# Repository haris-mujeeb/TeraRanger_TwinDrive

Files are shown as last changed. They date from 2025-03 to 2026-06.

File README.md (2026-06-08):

# Autonomous Maze Solving Robot 🤖

This project features a two-wheeled, self-balancing robot capable of autonomous navigation and maze solving. It uses a host-PC-based algorithm to build a 2D map of its environment in real-time.

The robot's hardware is a custom-designed, differential-drive platform based on an **Arduino Nano** for real-time balancing control and an **ESP32-S3** as a central communication hub. It uses a **TeraRanger Multiflex** Time-of-Flight (ToF) sensor array for 2D environmental mapping.

RobotFinalAssembly1

-----

## Demo
https://github.com/user-attachments/assets/0ca18e00-be7d-4444-9bbe-24fa2c01fbb0

-----

## System Architecture


-----

## ✨ Key Features
  * **Dynamic Self-Balancing**: Implements a robust **Multi-rate PID control** algorithm to ensure stable balancing and precise locomotion. The pitch control loop uses an **Adaptive Derivative Gain** to achieve high stability while eliminating jitter.
  * **Advanced Sensor Fusion**: Utilizes an **Extended Kalman Filter (EKF)** for accurate state estimation. It fuses data from the **MPU-6050** IMU (attitude) and **Hall-effect motor encoders** (odometry) to get a reliable estimate of the robot's pitch angle and position.
  * **Real-time 2D Mapping**: The host PC application integrates robot odometry with the **TeraRanger Multiflex** ToF sensor readings, building a 2D point cloud map of the environment on the fly.
  * **Live Data Visualization**: A custom **PyQtGraph** application provides a rich, interactive 2D plot displaying the robot's estimated position, historical path, and the mapped environmental points.
  * **Wi-Fi Communication Hub**: The ESP32-S3 acts as a **Soft Access Point (SoftAP)**, creating its own Wi-Fi network. It streams sensor telemetry and receives control commands over a low-latency **TCP socket** connection.
  * **Autonomous & Manual Control**: The robot can be driven manually via keyboard commands or operate autonomously, using the generated map and a **wall-following algorithm** to solve mazes.

-----

## 🛠️ System Architecture & Technologies

The system is split into two main parts: the on-board embedded controllers and the host PC application.

### 1\. Robot Hardware & Firmware (C++ / PlatformIO)

| Component | Role | Details |
| :--- | :--- | :--- |
| **Mobile Base** | **Arduino Nano** | The low-level controller responsible for real-time balancing and motion. It runs the high-frequency, multi-rate PID control loops. |
| **Comm. Hub** | **ESP32-S3-DevKitC-1** | The high-level controller and main hub. It aggregates data from the Arduino Nano and ToF sensors, and manages the Wi-Fi (SoftAP) TCP connection to the PC. |
| **Attitude Sensor** | **MPU-6050 IMU** | Provides 6-axis accelerometer and gyroscope data for orientation and pitch angle estimation. |
| **Mapping Sensor** | **TeraRanger Multiflex** | An array of 8 ToF (Time-of-Flight) sensors used for 2D environmental mapping. |
| **Odometry Sensors** | **Hall-Effect Encoders** | Integrated into the DC motors, they provide precise odometry (distance and speed) measurements. |

### 2\. Host PC Application (Python)

  * **Logic**: **Python** for the main application, mapping algorithms, and maze-solving logic.
  * **GUI**: **PyQt5** for the application window and user controls.
  * **Visualization**: **PyQtGraph** for high-performance, real-time 2D plotting of the map and robot state.
  * **Data Processing**: **NumPy** for efficient numerical operations.

-----

## 📂 Project Structure

```
.
├── communication_hub_code/  # Firmware for the ESP32-S3 (Wi-Fi, Sensor Hub)
├── mobile_base_code/        # PlatformIO project for the Arduino Nano (Balancing, Motor Control)
├── tests/                   # Test scripts and code
├── videos/                  # Demo videos
├── .gitignore
├── LICENSE
├── logger_config.py         # Logging configuration
├── main.py                  # Main Python application entry point (Visualization)
├── mazeSolver.py            # Autonomous maze solving logic
├── README.md                # This file
├── requirements.txt         # Python dependencies
└── robotInterface.py        # Interface for robot (TCP) communication and control
```

-----

## 🚀 Installation & Setup

### 1\. Clone the Repository

```bash
git clone https://github.com/haris-mujeeb/Maze_Solver.git
cd Maze_Solver
```

### 2\. Install Python Dependencies

```bash
pip install -r requirements.txt
```

### 3\. Robot Firmware Setup (Crucial)

You will need **[PlatformIO](https://platformio.org/)** (ideally as a VS Code extension) to build and upload the firmware for both microcontrollers.

#### A. Mobile Base (Arduino Nano)

This firmware handles the core self-balancing and motor control.

1.  Open the `mobile_base_code/` directory in VS Code with PlatformIO.
2.  Connect your **Arduino Nano**.
3.  Build and upload the project.

#### B. Communication Hub (ESP32-S3)

This firmware manages sensor data aggregation and Wi-Fi communication.

1.  Open the `communication_hub_code/` directory in VS Code with PlatformIO.
2.  Connect your **ESP32-S3-DevKitC-1**.
3.  Build and upload the project.
4.  This firmware will create a Wi-Fi Access Point (SoftAP). The default IP address is typically `192.168.4.1`.

-----

## ⚙️ Configuration

The network settings for Wi-Fi communication are defined in `main.py`. These must match your robot's network configuration.

```python
# main.py
RECEIVE_HOST = '0.0.0.0'  # PC: Listen on all available interfaces for incoming robot data
RECEIVE_PORT = 12346      # PC: Port for receiving telemetry data (via TCP)
SEND_HOST = '192.168.4.1' # ROBOT'S IP: Default IP for ESP32-S3 SoftAP mode
SEND_PORT = 12345         # ROBOT'S PORT: Port for sending commands (via TCP)
```

  * **`SEND_HOST`**: This **must be the IP address of your ESP32-S3**. If you are connecting your PC directly to the robot's Wi-Fi network (SoftAP mode), this will be `192.168.4.1`.
  * Ensure the ports match those configured in the ESP32-S3 firmware.

-----

## 🕹️ Usage

1.  **Power on the robot**. The Arduino Nano will begin balancing, and the ESP32-S3 will start its Wi-Fi Access Point.
2.  **Connect your PC** to the Wi-Fi network created by the ESP32-S3.
3.  **Run the main application** on your host PC:
    ```bash
    python main.py
    ```
4.  **Control the robot:**
      * The PyQtGraph application will launch, showing the live visualization.
      * Use the following keyboard commands for manual control:
          * **W**: Move forward
          * **S**: Move backward
          * **A**: Turn left
          * **D**: Turn right
          * **R**: Stop
          * **G**: Go to a manually entered target (prompts for X, Y coordinates)
      * You can also **left-click on the plot** to set a target position for the robot to navigate to autonomously.

## Contributing

Contributions are welcome\! Please feel free to submit a pull request or open an issue if you have any suggestions or find any bugs.

## License

This project is licensed under the MIT License. See the [LICENSE](https://www.google.com/search?q=LICENSE) file for details.

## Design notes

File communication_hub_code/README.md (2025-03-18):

Continuously sends telemetry data (robot yaw, distance, etc.) to connected clients and reponds to the commands for controlling the robot's movement (e.g., TURN, MOVE).

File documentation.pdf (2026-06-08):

## Universität Siegen Naturwissenschaftlich-Technische Fakultät Department Elektrotechnik und Informatik Lehrstuhl für Regelungs- und Steuerungstechnik

## Studienarbeit

# Design and Fabrication of Remotely

# Operated Two-Wheeled Self-Balancing

# Robot with Integrated ToF Sensor

# Array for 2D Mapping

by

Muhammad Haris Mujeeb

Matriculation number

1721876

Examiner

Prof. Dr.-Ing. habil. Michael Gerke

2nd Examiner

Dipl.-Ing. Nasser Gyagenda

Date of delivery

12.05.2025

Abstract—This report presents the design and implementation of a remotely controlled two-wheeled self-balancing robot with TeraRanger Multiflex, consisting of eight Time-of-Flight (ToF) sensors for two-dimensional (2D) environmental mapping. The system

architecture comprises a differential-drive mobile base, a ToF sensors array for spatial perception and an embedded communication and control hub for data integration and external interfacing. The mobile base consists of a pair of DC motors, an Arduino Nano microcontroller, an Inertial Measurement Unit (IMU) and Hall-effect rotary encoders to provide accurate state estimation. A Multi-rate Proportional-Integral-Derivative (PID)

control algorithm is employed to ensure stable balancing and precise locomotion control. The ESP32-S3-DevKitC-1 serves as the central communication and control hub, enabling efficient data exchange between the two-wheeled mobile base, the ToF sensor array, and external systems such as computers, microcontrollers, mobile devices, or cloud services. This setup facilitates real-time monitoring and remote control via Wi-Fi, thereby enhancing the system’s adaptability across various applications. The firmware for both the Arduino and ESP32-based microcontrollers was developed using PlatformIO (https://platformio.org/) and Arduino IDE. (https://www.arduino.cc/en/software) The

robot continuously transmits telemetry and ToF sensors data while receiving commands through Wi-Fi. The complete project, including source code and detailed documentation, is available at the following GitHub repositories:

- https://github.com/haris-mujeeb/Self-Balancing-Robot
- https://github.com/haris-mujeeb/TeraRanger-Multiflex-DEMO
- https://github.com/haris-mujeeb/TeraRanger_TwinDrive

i

## Contents

1 Introduction | 1
2 Project Objectives | 2
3 Literature Review | 2
4 Mathematical Modelling | 4
5 Implementation | 7
6 Sensor Fusion | 16
7 Motor Control | 21

ii

8 Front Obstacle Detection | 30
9 Communication Hub | 36
10 Conclusion | 41
11 Future Work and Improvements | 42
Appendices | 43
A Calculation of the system’s transfer functions | 43
B Calculation for Kalman Filter | 46

iii

iv

## List of Figures

Fig. 1 | Forecast of the MEMS market value in billions of US dollars by year. Reproduced
| from an open-access source [3] | | 1
Fig. 2 | ELEGOO Tumbler used as the mobile base for this project [7] | | 3
Fig. 3 | TeraRanger Multiflex circular mount [18] | | 3
Fig. 4 | ESP32-S3-DevKitC-1-N8R8 from Espressif Systems[19] | | 3
Fig. 5 | Simplified inverted pendulum model for the balancing robot [8] | | 4
Fig. 6 | Pole-zero map of the open loop system Gψ revealing a pole in the right half plane. | 5
Fig. 7 | A simplified block diagram of the system architecture | | 7
Fig. 8 | A simplified flow diagram of the system architecture | | 8
Fig. 9 | (a) ATmega328p microcontroller by Microchip [21]; (b) Arduino Nano board by
| Arduino [22] | | 9
Fig. 10 ELEGOO chargeable battery pack | | 10
Fig. 11 Schematic of the voltage divider circuit utilised in this project. The voltage VM is
| connected to the positive terminal of the battery, while VOL is connected to the
| Arduino Nano A2 pin [7] | | 10
Fig. 12 MPU-6050 6-axis IMU [24] | | 11
Fig. 13 (a) TB6612FNG motor driver [26]; (b) SN74LVC2G14 dual Schmitt-trigger
| inverter [27] | | 12
Fig. 14 Target characteristics for TB6612FNG [25] | | 12
Fig. 15 Schmitt trigger output without hysteresis (left) and with hysteresis (right) [28]. . . | 13

Fig. 16 Using SN74LVC2G14 in conjunction with TB6612FNG to reduce MCU pin usage
| and noise filtering [7] | | 13
Fig. 17 NHYTech GA37 520 DC motor [29] | | 13
Fig. 18 (a) IR204C-A infrared LED [31]; (b) IRM-56384 infrared reciever [32] | | 14
Fig. 19 (a) HC-SR04 ultrasonic distance sensor [30]; (b) Bluetooth module [33] | | 14

Fig. 20 Pitch angle calculated using a complementary filter with α = 0.9. It can be
| observed that the high frequency accelerometer noise (circled in red) are filtered
| properly. And similarly the low frequency integration errors of the gyroscope (red)
| are removed over longer interval of time | | 17
Fig. 21 Block diagram for pitch angle ψ control | | 21
Fig. 22 A simplified flow diagram of the multi-rate PID control loop used | | 24
Fig. 23 Output values calculated by the pitch angle PD controller at Kpψ = 55 and Kdψ =
| 1.25. The data was recorded at baud rate of 115200 | | 25
Fig. 24 Output values calculated by the pitch angle PD controller at Kpψ = 55 and Kdψ =
| 0.75. Data recorded at baud rate of 115200 | | 25
Fig. 25 Output values calculated by the pitch angle PD controller with an adaptive
| derivative gain at Kpψ = 55 and Kdψ = 0.75 ∼ 1.25. The data was recorded
| at baud rate of 115200 | | 26
Fig. 26 Yaw angle control system response at Kp = 2.5 and Kd = 0.5 for angle varying
| from −20 deg to +20 deg. The data was recorded at baud rate of 115200 | | 27

v

Fig. 27 Position control system response with Kpx = 0.26 and Kdx = 20 for a displacement
of −600 mm to +300 mm. Data recorded at baud rate of 115200 | | 29
Fig. 28 A simplified diagram of the motor control loop [35] | | 29
Fig. 29 The received raw data from the TerraRanger Multiflex via UART | | 38
Fig. 30 Real-time sensor data visualization in a polar plot | | 39
Fig. 31 Final assembly of the remotely operated two-wheeled robot with TeraRanger
Multiflex | 41
Fig. 32 Free-body diagram of the simplified system with cart and pendulum [35]. Where, x axis is along the horizontal axis and y axis is along the vertical axis and ψ = π − θ. 43

vi

## List of Tables

Tab. 1 | UART Communication Configuration | | 15
Tab. 2 | I2C Communication Methods | | 36
Tab. 3 | UART Communication Methods | | 37
Tab. 4 | List of Commands and Corresponding Values | | 37

vii

1. Introduction

## 1. Introduction

The World Robotics report reveals a record 4.28 million operational industrial robots globally in 2023, with Asia leading installations at 70%, driven primarily by China’s significant market share, while

overall demand for robots is expected to stabilize and grow in the coming years despite geopolitical uncertainties [1]. The mobile robot market, particularly for autonomous mobile robots (AMRs), is

experiencing rapid growth across industrial and commercial sectors, with the overall AMR market projected to grow at 24% annually—from $19 billion in 2018 to $54 billion by 2023 [2]. Driven

initially by automotive and electronics sectors, demand is now expanding into logistics, healthcare, and consumer goods, with Europe leading the market and significant contributions from the USA and China [2].
Over the past decade, advancements in Micro-Electro-Mechanical Systems (MEMS) and embedded

computing have revolutionized the design and functionality of robots. Membrane-based MEMS, such as pressure sensors, radio frequency MEMS, accelerometers, microphones, gyroscopes and inertial combos are commercially the most relevant devices by producing the most revenue as shown in Fig. 1.

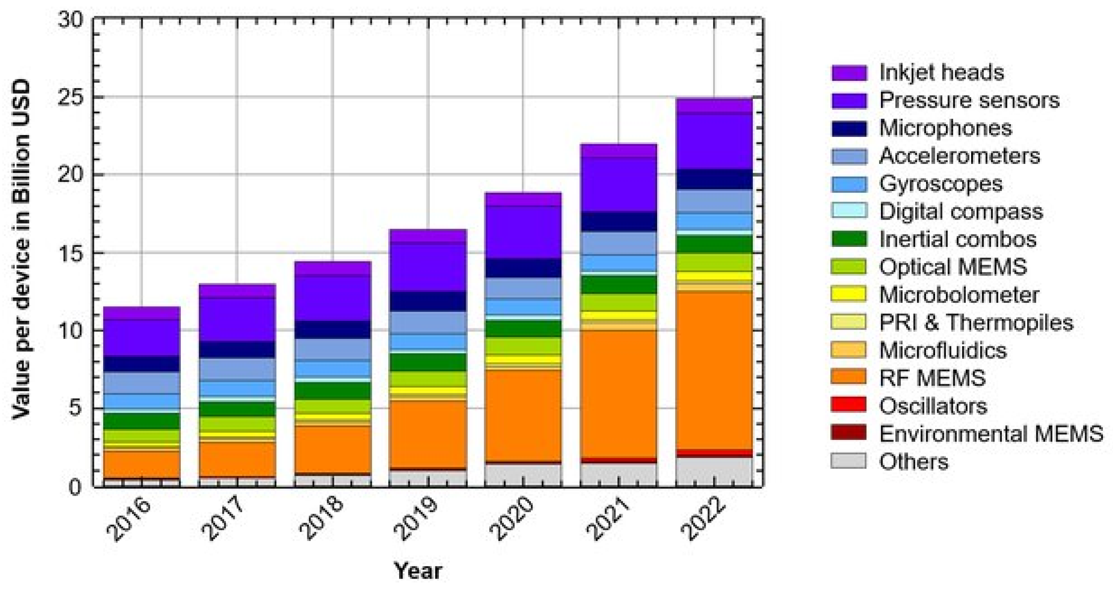
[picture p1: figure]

Figure 1: Forecast of the MEMS market value in billions of US dollars by year. Reproduced from an open-access source [3].

The worldwide MEMS market is expected to grow to $64.15 billion by 2035 [4]. These advancements

in MEMS and embedded computing have also revolutionized the design and functionality of mobile robots. For instance, the introduction of gyros, accelerometers, and other sensors has enabled these robots to achieve higher levels of balance and stability. One interesting area of research is the integration of cost effective Time-of-Flight (ToF) sensors, a type of Optical MEMS sensors, with

mobile base. These sensors are particularly useful for applications requiring 2D mapping, such as navigation, localization, and obstacle detection.
Therefore, research into the design and fabrication of a low-cost, user-friendly mobile robot base equipped with ToF sensors is both timely and strategic. Such a platform would provide accessible entry points for education, research, and small-to-medium enterprises looking to adopt robotic automation, bridging the gap between high-end industrial solutions and affordable, scalable alternatives.

3. Literature Review

## 2. Project Objectives

The primary objectives of this project are:

- To design and implement a two-wheeled self-balancing mobile platform capable of maintaining dynamic stability using real-time sensor feedback and control algorithms.
- To develop a robust control framework that ensures precise balancing and smooth motion control, with resilience to external disturbances.
- To integrate an Inertial Measurement Unit (IMU) and Hall-effect rotary encoders, utilizing

sensor fusion techniques such as the Kalman filter, to achieve accurate state estimation, including orientation and velocity.

- To enhance the robot’s spatial awareness through 2D environmental mapping using Time-of-Flight (ToF) sensors.
- To develop a central communication and control hub, facilitating data integration between the mobile base, ToF sensors, and external systems, enabling real-time monitoring and remote control over Wi-Fi.
- To provide comprehensive documentation of the system design, control strategies, and software implementation, and to openly share the source code and resources via GitHub to support reproducibility and future development.

## 3. Literature Review

Wheeled robots are inherently more efficient than bipedal counterparts due to their lower energy consumption, simpler mechanics, and reduced control complexity. This makes them not only more cost-effective to produce and maintain but also highly suitable for structured indoor environments where agility and compactness are essential [5]. Today, robots are used in a variety of environments

beyond industrial and clinical settings, including everyday locations such as offices, hotels, hospitals, and homes, where they frequently interact with people. In these situations, mobile robots frequently need to manoeuvrer effectively within limited spaces [6]. Therefore, a two-wheeled robot was selected for the mobile base for this research project. The ELEGOO Tumbler (https://www.elegoo.com/products/elegoo-tumbller-self-balancing-robot-car) (shown in Fig. 2) was selected

as a base platform, as it provides nearly all the necessary hardware in a convenient DIY kit. Two-wheeled self-balancing robots have been widely studied as a variant of the classic inverted pendulum problem, requiring control strategies to maintain stability. Various approaches, including Proportional-Integral-Derivative (PID) control [8], Lead-Lag [9] and Fuzzy Control [10] have been explored to achieve robust balancing and motion control. Abdelgawad et al. [11] demonstrated that

PID control offers higher accuracy, lower error, faster response, and greater robustness, while also being easier to tune—making it well-suited for precise control applications. Kalman filter [12] has been shown to significantly enhance state estimation accuracy [13], [14], [15], and is therefore also

employed in this project.
This project, we aim to develop a lightweight and efficient system for 2D environmental mapping in compact indoor settings. For Time-of-Flight (ToF) sensing, the Terabee TeraRanger Multiflex (shown

3. Literature Review

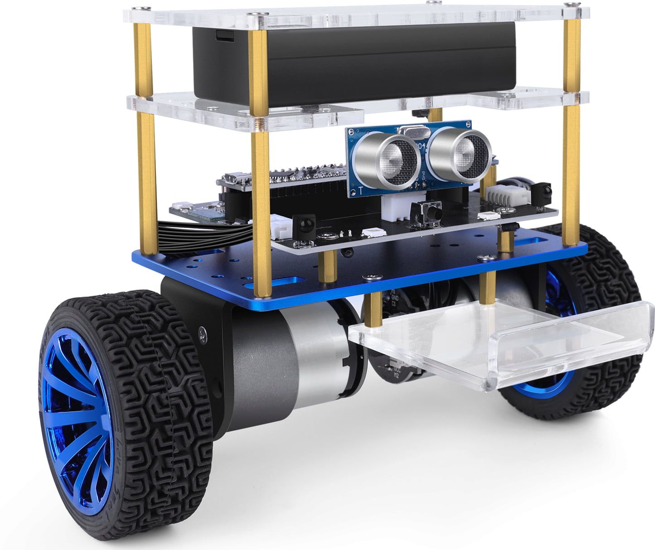
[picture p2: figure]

Figure 2: ELEGOO Tumbler used as the mobile base for this project [7].

in Fig. 3) was selected due to its reliable range of up to 2 meters and its modular design featuring eight pre-calibrated, plug-and-play sensors [16]. These characteristics make it particularly well-suited for applications that require low power consumption and scalability. The ESP32-S3-DevKitC-1 (shown in Fig.4) was similarly selected as the communication hub for its open-source support, integrated Wi-Fi, and dual-core processing [17]. These capabilities enable efficient real-time data handling and

peripheral communication, which are critical for processing input from the sensors and forwarding.

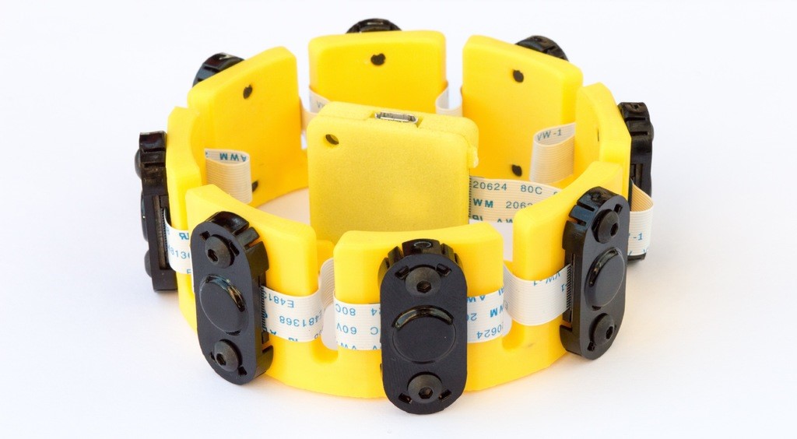
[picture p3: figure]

Figure 3: TeraRanger Multiflex circular mount [18].

Figure 4: ESP32-S3-DevKitC-1-N8R8 from Espressif Systems[19].

4. Mathematical Modelling

## 4. Mathematical Modelling

The balancing robot is typically represented as a rigid rod attached to a joint, mounted on a rigid cart that moves in a single direction. For simplification, the wheelbase of the robot is assumed to behave like a cart sliding on a frictionless surface, as shown in Fig. 5. This modelling approach follows Prasad and Tyagi [20], and the MathWorks [8].

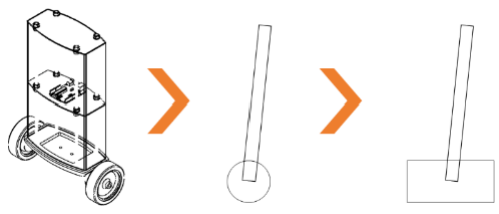
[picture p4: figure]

Figure 5: Simplified inverted pendulum model for the balancing robot [8].

### 4.1. State Equations

The state space form of the robot is given by,

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
+ Buinput | (1)
y = C uinput | (2)

Using the free-body diagram for the simplified inverted pendulum model, as illustrated in Fig. 32, the system matrices A, B and C were derived as,

A =

0 | 1 | 0 | 0
0 | −(Ipend+mpendl

2
)f
| Ipend(mcart+mpend)+mcartmpendl

2

m²

| | pendgl² Ipend(mcart+mpend)+mcartmpendl
2 | 0
0 | 0 | 0 | 1
0 | −mpendlf Ipend(mcart+mpend)+mcartmpendl
2
| | mpendgl(mcart+mpend) Ipend(mcart+mpend)+mcartmpendl
2 | 0

(3)

B =

0

Ipend+mpendl

2

Ipend(mcart+mpend)+mcartmpendl

2
0

mpendl
Ipend(mcart+mpend)+mcartmpendl

2

(4)

C =

"
1 0 0 0

0 0 1 0#
(5)

4. Mathematical Modelling

For complete derivation of A B and C, see Appendix A. After Laplace transformation, linearisation and combining the equation of motion for the pendulum (Eq. 38) and equation of motion for the cart (Eq. 39), we get the transfer function Gψ(s) for vertical angle of the robot Ψ(s),

Ψ(s) =

mpendl
q

s

s

3 +

f(Ipend+mpendl

2)
q

s

2 −

(mcart+mpend)mpendgl
q

s −

fmpendgl
q
| | {z | }
| Gθ(s)

Uinput(s)

and the transfer function Gx(s) horizontal cart position X(s),

X(s) =

(Ipend+mpendl

2
)s

2−gmpendl
q
s

4 +

f(Ipend+mpendl

2)
q

s

3 −

(mcart+mpend)mpendgl
q

s

2 −

fmpendgl
q

s
| | {z | }
| Gx(s)

Uinput(s)

Where f is friction coefficient, l is the distance to the centre of mass, Ipend is the moment of inertia of the pendulum, mcart is the mass of the cart, mpend is the mass of the pendulum, g is the acceleration due to gravity and q is defined as q = (mcart + mpend)(Ipend + mpendl

2
) − (mpendl)

2
, as illustrated in
Fig. 32.
Using MATLAB, pole zero map for the open loop system Gψ can be generated (see Fig. 6). It is

concluded that for all positive value of f, l, Ipend, mcart, mpend and g the system in itself is unstable since it has a pole on the positive real axis as can be seen in Figure 6.

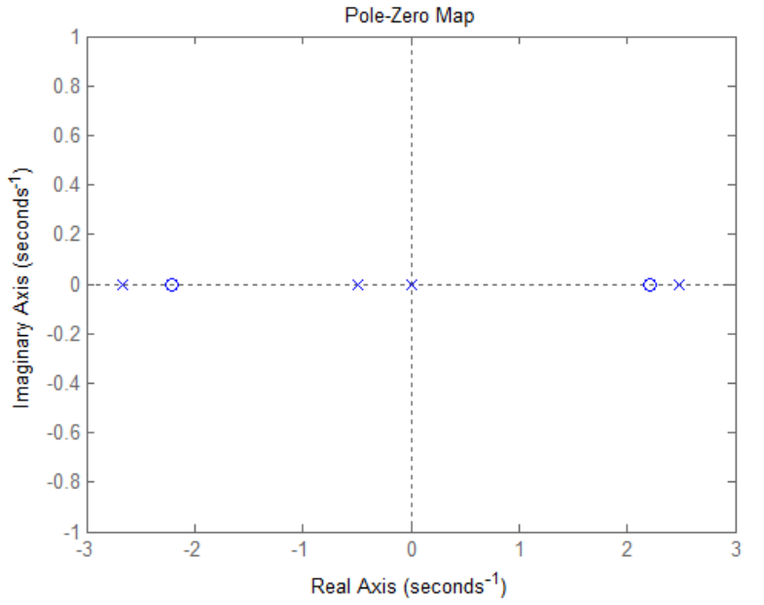
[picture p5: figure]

Figure 6: Pole-zero map of the open loop system Gψ revealing a pole in the right half plane.

4. Mathematical Modelling

### 4.2. Controllability and Observability

Controllability ensures that the system can be driven from any initial state to any desired state using a suitable control input. Observability guarantees that the system’s internal states can be reconstructed from its outputs. These properties are determined by the rank of the controllability matrix S and the observability matrix O, respectively. If both matrices S and O have full rank, then the system is fully controllable and observable.
S =

h
B AB A²B A³B

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
Using the system matrices A, B and C (see equations 49, 50 and 51 in Appendix A), the rank of S

and O confirms that the system is controllable and observable for any positive value of l, Ipend, mcart, mpend and g.

5. Implementation

## 5. Implementation

The system architecture of the robot can be divided into three parts Mobile Base, TerraRanger Multiflex Hub and Communication Hub as shown in Fig. 7. This robot can also communicate with external systems such as computers, microcontrollers, mobile devices, or cloud services via Wi-Fi.

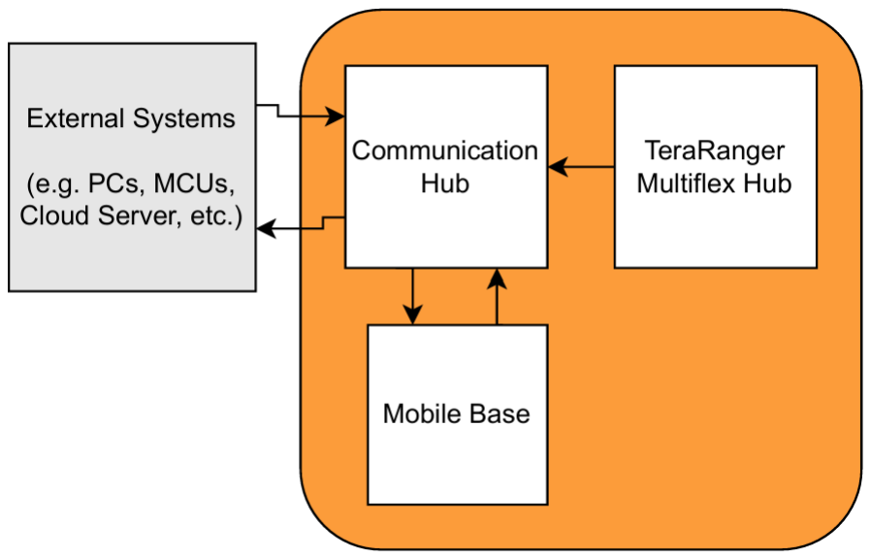
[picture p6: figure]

Figure 7: A simplified block diagram of the system architecture.

### 5.1. Software Implementation

The Figure 8 illustrates the overall system architecture and control flow for the self-balancing mobile base. The process begins with system initialisation and calibration of its various sensors. Sensor data, including encoder values, IMU data, and obstacle distance, is acquired and passed through respective filters (Weighted Moving Average (WMA), Kalman, and Binary Counting) to reduce noise and improve

accuracy. The filtered sensor data is then aggregated and used to update the robot’s internal state. Subsequently, the user commands are received, parsed and processed.
To stabilize the inverted pendulum in the upright position and to control the robot at the desired position and yaw angle, three PID controllers, each dedicated to managing one of these parameters. The PID control algorithm (shown in Fig. 22) utilises the updated sensor data to calculate appropriate

motor commands. These commands are then sent to the motors, driving the robot’s movement. Throughout this process, telemetry data is generated and transmitted, providing feedback on the robot’s status and performance. The refined distance data is then transmitted to the Communication Hub via a UART interface.
TeraRanger Multi-flex Hub reads the raw ToF measurements from the sensors array and processes them using data onboard filtering algorithms to improve accuracy. This processed data is then send to the Communication Hub.
The Communication Hub acts as the central gateway, relaying sensor data to external systems (e.g., computers, cloud services) and forwarding control commands from these systems to the mobile base.

It employs a bidirectional Wi-Fi protocol to ensure low-latency data exchange, facilitating real-time remote supervision and intervention when necessary.

5. Implementation

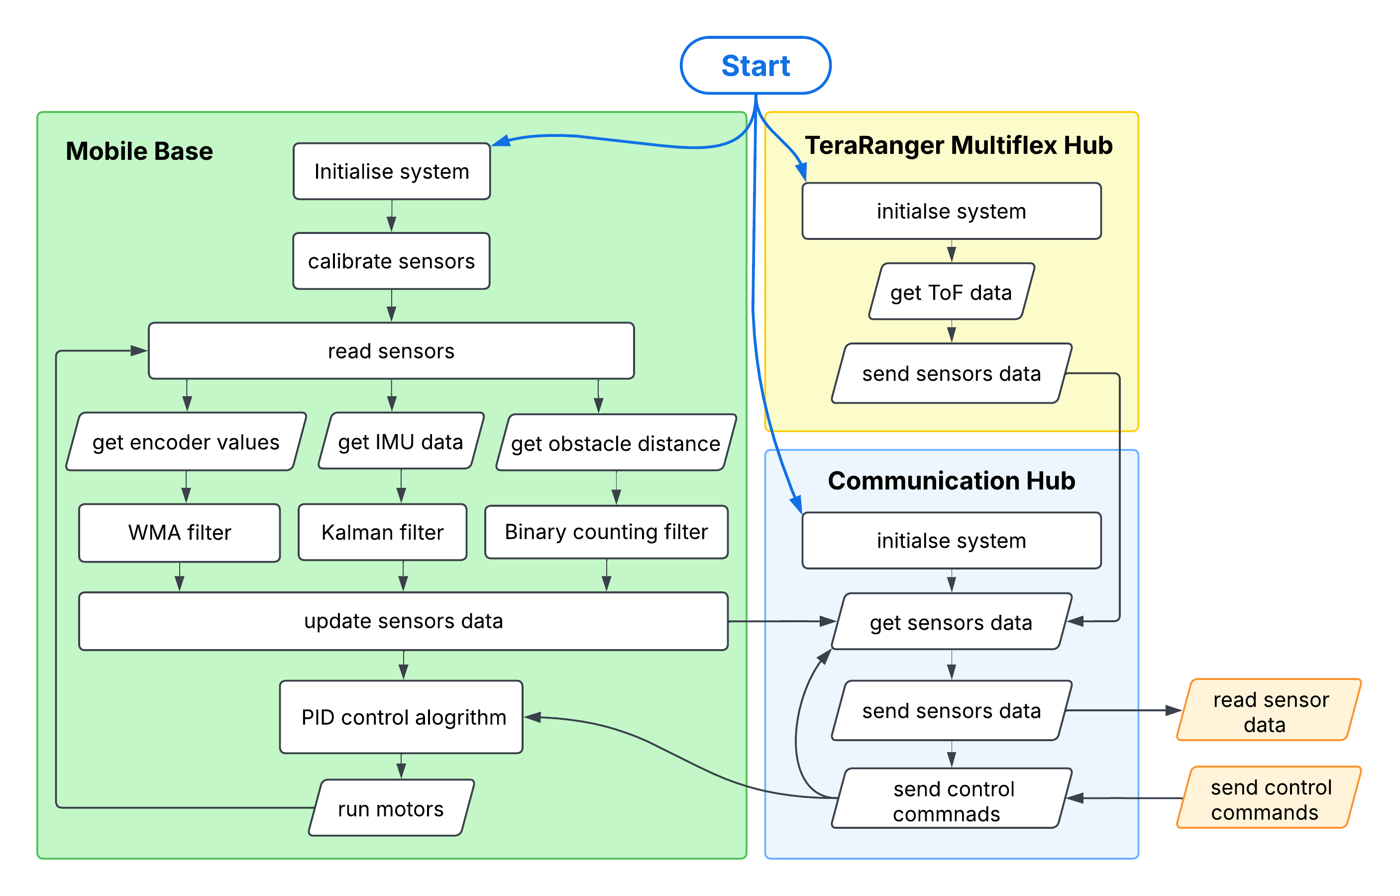
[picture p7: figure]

Figure 8: A simplified flow diagram of the system architecture.

### 5.2. Hardware Implementation

The system integrates a modular hardware architecture centered on the Arduino Nano (ATmega328P)

for low-level motor control and sensor interfacing, complemented by the ESP32-S3-DevKitC-I as a high-performance communication hub. Key components include:
Sensing and Perception:
- MPU6050 (6-axis IMU) for real-time attitude estimation via fused accelerometer/gyroscope data.
- HC-SR04 ultrasonic and infrared (IR) sensors for front obstacle detection, enabling reactive

navigation.

- TeraRanger Multi-flex for 2D mapping, interfaced via UART.

Actuation and Control:

- TB6612FNG motor driver for driving DC gear motors with Hall-effect encoders.
- PID control loops (running on the Arduino Nano) for balancing, rotation and position control.

Communication:

- BT16 Bluetooth module for short-range telemetry and configuration.
- ESP32-S3-DevKitC-I managing Wi-Fi/Bluetooth LE connectivity, enabling remote monitoring

and cloud integration.

5. Implementation

Power Management:

- Two 18650 Lithium Polymer (LiPo) batteries (7.4 volts nominal) with integrated BMS for overcharge/discharge protection, supplying regulated 5 volts rails to peripherals.

### 5.2.1. Microcontrollers

This project utilizes two microcontrollers: the ATmega328P and the ESP32-S3. The ATmega328P, integrated into the Arduino Nano (Fig. 9), serves as the primary controller for the two-wheeled mobile

base. It handles real-time tasks such as sensor data acquisition, filtering, motion control, and basic communication. With a 16 MHz clock, 32 KB of flash memory, 2 KB SRAM, and 1 KB EEPROM [21],

it provides sufficient resources for embedded control tasks in this application. The Arduino Nano, based on the ATmega328P, was chosen for its compact form factor, low cost, and strong community support, making it ideal for prototyping and rapid integration with sensors, encoders, and motor drivers [22].

It communicates with the ESP32-S3 via UART at 9600 bps, transmitting control commands and

telemetry data.

(a) (b)

Figure 9: (a) ATmega328p microcontroller by Microchip [21]; (b) Arduino Nano board by Arduino [22]

The ESP32-S3, integrated into ESP32-S3-DevKitC-1 (Fig. 4), serves as the central communication

and processing hub. It interfaces with the TeraRanger Multiflex Hub over a separate UART channel at 115200 bps, enabling high-speed data transfer from the ToF sensor array. Additionally, its onboard

Wi-Fi capability allows remote access and real-time data exchange with external systems—such as computers, microcontrollers, or cloud services—using an Access Point (AP) configuration.

Both the ESP32-S3 and the TeraRanger Multiflex are powered by the same battery supplying the mobile base, streamlining the power architecture and ensuring reliable operation in mobile scenarios.

### 5.2.2. Power Supply

The custom-designed battery box, illustrated in Fig. 10, offers a portable and rechargeable power solution for the Elegoo robot [23]. It accommodates two 18650 LiPo batteries, configured in series to

provide a regulated nominal voltage of 7.4 volts, which is suitable for powering all robot components, including the mobile base, the TeraRanger Multiflex Hub and the ESP32-S3-DevKitC-1. An integrated Battery Management System (BMS) ensures safe operation by protecting against overcharging, over-

discharging, over-current conditions, and short circuits. Additionally, a power switch enables complete disconnection of the power supply, while a USB charging port and a status indicator LED facilitate convenient recharging and monitoring of the battery’s status.

5. Implementation

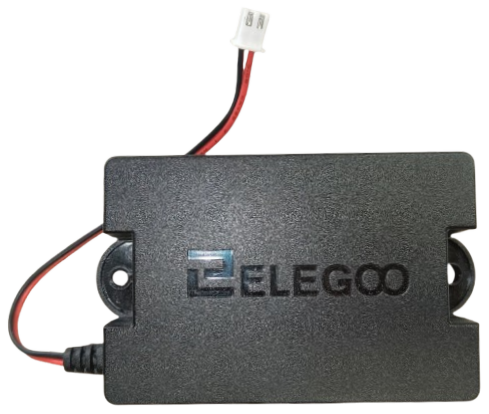
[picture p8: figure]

Figure 10: ELEGOO chargeable battery pack.

The battery voltage level can be monitored using 10-bit ADC available in ATmega328P [21]. But

ATmega328P works within the voltage range of 0-5 volts. For this reason, a voltage divider circuit is

employed, as shown in Fig. 11.

Figure 11: Schematic of the voltage divider circuit utilised in this project. The voltage VM is connected to the positive terminal of the battery, while VOL is connected to the Arduino Nano A2 pin [7].

The voltage divider circuit, depicted in Fig. 11, comprises of two resistors connected in series. The output voltage is expressed as follows:

Vout = Vbattery ×

R2
R1 + R2

(8)

Where Vout is the scaled-down voltage read by the ADC of the Arduino Nano, while R1 and R2

are the resistor values selected to ensure the measured voltage remains within the 0–3.3 volts range. Specifically, a series configuration of 10 kΩ (R1) and 1.5 kΩ (R2) resistors is utilised, resulting in a

voltage division ratio of approximately 1:11.

Vout = Vbattery ×

1.5
10 + 1.5
= Vbattery × 0.136 | (9)

For a fully charged 8.4 V LiPo battery, the resulting output voltage Vout is approximately 1.1 volts. This adjustment aligns the measured voltage more closer with the internal reference voltage of 1.1 volts, as specified in the data-sheet [21]. This ensures stable readings independent of supply voltage

fluctuations, but may introduce minor ADC saturation at peak voltage.
An algorithm, similar to the one illustrated in Alogrithm 1, is employed that periodically measures the voltage at Arduino Nano pin A2 and sends an error message "Low battery" if it falls below a defined threshold.

5. Implementation

Algorithm 1 Voltage Monitoring and Motor Shutdown
1: procedure CheckVoltageLevel(lastCheckT ime)
2: | if current time − lastCheckT ime > V OLT AGE_CHECK_INT ERV AL then
3: | Read voltageV alue from ADC
4: | Update lastCheckT ime to current time
5: | if voltageV alue ≤ MINIMUM_ALLOW ED_V OLT AGE then
6: | Stop motors
7: | Display error message: “Voltage low!”
8: | Set robotState ← ERROR
9: | end if
10: | end if
11: end procedure

### 5.2.3. Inertial Measuring Unit

The MPU6050 is a widely used 6-axis Inertial Measurement Unit (IMU) that integrates a three-axis

gyroscope and a three-axis accelerometer on a single chip, making it essential for motion tracking and stabilization applications (shown in Fig. 12). Its compact design and built-in Digital Motion Processor (DMP) enable real-time processing of sensor data, which is crucial for robotics, drones, and wearable

devices. In applications like self-balancing robots, it provides accurate orientation and acceleration data necessary for maintaining stability.

Figure 12: MPU-6050 6-axis IMU [24].

The MPU6050 is an IMU that provides the following data:

- Accelerometer Data: Measures acceleration in X, Y, and Z axes. It helps in estimating tilt based on gravitational force.
- Gyroscope Data: Measures angular velocity around X, Y, and Z axes. Integration of gyroscope readings over time provides the tilt angle.

However, the raw sensor data from an IMU presents several challenges:

- Accelerometer Noise: Although accelerometers provide an absolute angle reference, their readings are often noisy and susceptible to external forces, which can affect accuracy.
- Gyroscope Drift: Over time, integration errors accumulate, leading to drift and resulting in inaccurate angle estimations.

To address these issues, sensor fusion techniques are employed, combining data from both the accelerometer and gyroscope to enhance accuracy and stability. These techniques are disscussed in more detial in Section 6.

5. Implementation

### 5.2.4. Motor Driver IC

The TB6612FNG dual motor driver, as shown in Fig. 13a, allows independent control of two DC motors. It uses a MOSFET H-bridge for bidirectional and Pulse Width Modulation (PWM) based

motor speed control. Fig. 14 shows that each channel of the TB6612FNG can deliver up to 0.85A of current continuously. Furthermore, it consists of integrated over-current protection and thermal shutdown features for enhance reliability [25].

### 5.2.5. Inverted Schmitt Trigger

To simplify direction control, an inverted Schmitt trigger allows a single MCU pin to generate both the control signal and its complement, eliminating the need for a second pin. The SN74LVC2G14 inverter, shown in Fig. 13b, is used for this purpose. Additionally, it enhances motor control by filtering noise

and providing cleaner signal transitions, improving stability, as illustrated in Fig. 15.

(a) (b)

Figure 13: (a) TB6612FNG motor driver [26]; (b) SN74LVC2G14 dual Schmitt-trigger inverter [27].

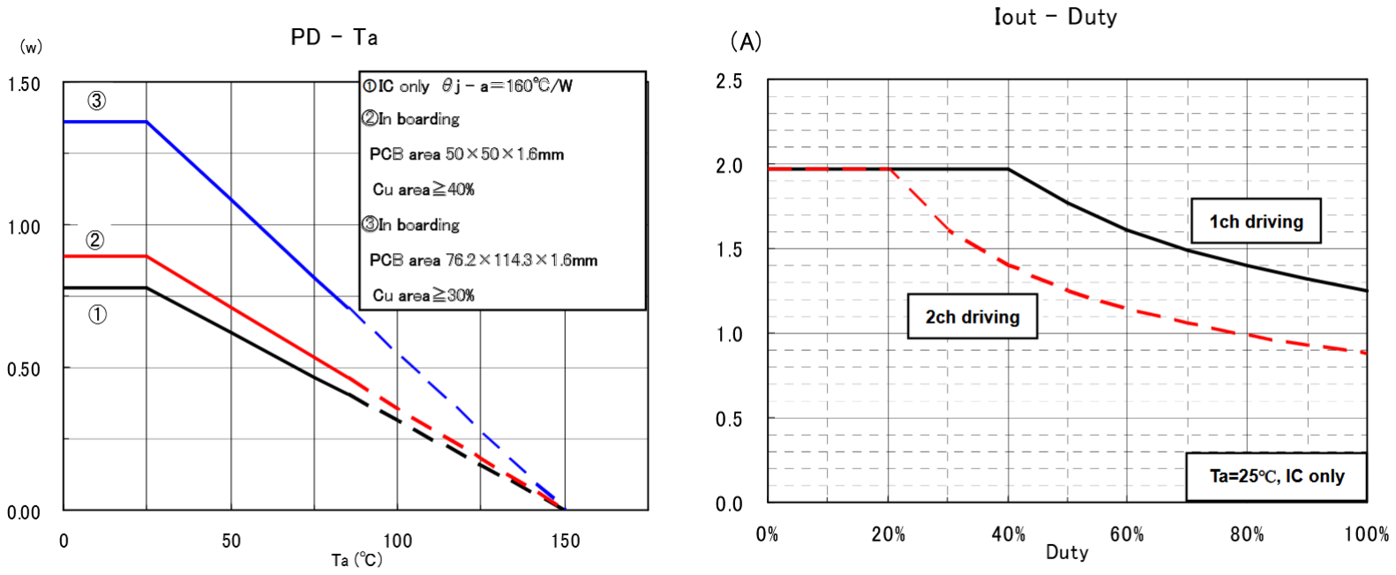
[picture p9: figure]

Figure 14: Target characteristics for TB6612FNG [25].

5. Implementation

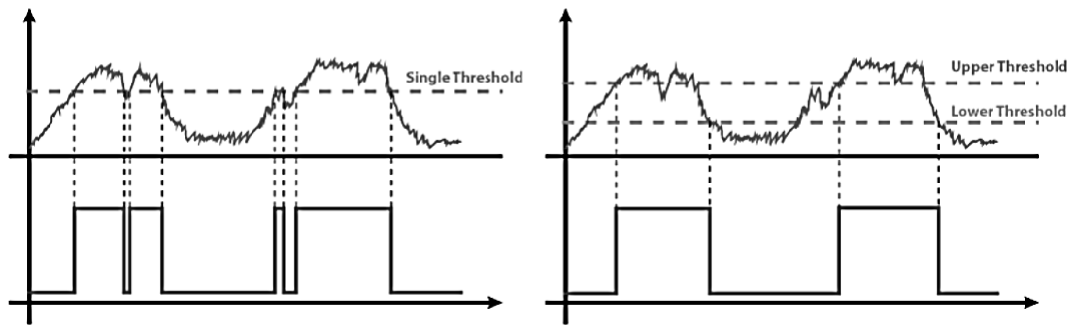
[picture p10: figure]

Figure 15: Schmitt trigger output without hysteresis (left) and with hysteresis (right) [28].

When used in conjunction with the TB6612FNG H-Bridge, the SN74LVC2G14 automatically generates the complementary control signals required for motor direction, reducing the number of MCU pins from four to two. As illustrated in Fig. 16, the AIN2 signal is inverted to produce AIN1, and BIN2 is inverted to produce BIN1, eliminating the need for separate MCU outputs for each.

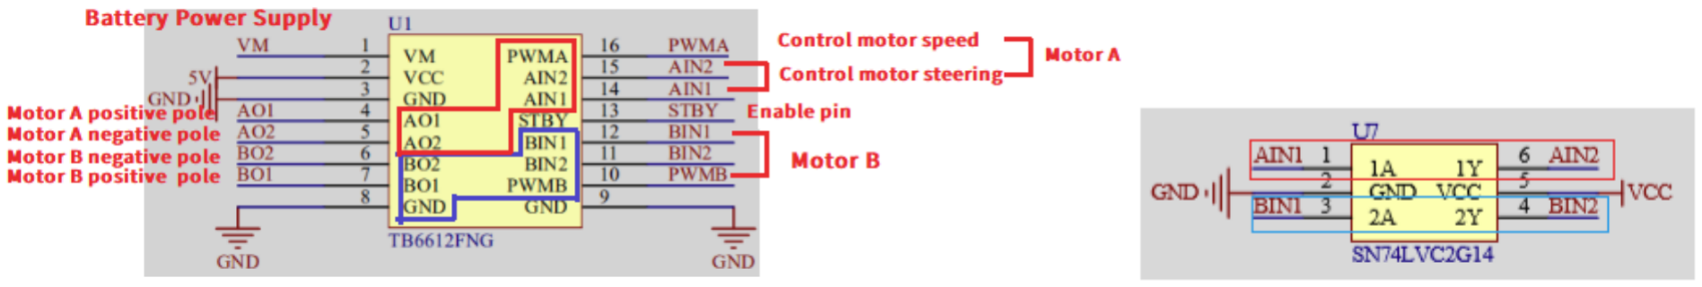
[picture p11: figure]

Figure 16: Using SN74LVC2G14 in conjunction with TB6612FNG to reduce MCU pin usage and noise filtering [7].

### 5.2.6. DC Drive Motors

The drive system employs NHYTech GA37 520 DC motors (37mm diameter, 12V, 360 RPM) equipped with Hall effect encoders (shown in Fig. 17) [29]. These motors feature a reduction gearbox, which

enhances torque output while maintaining controlled rotational speed, making them well-suited for applications requiring precise motion control. The Hall-effect encoders generate quadrature signals, enabling accurate measurement of speed and position.

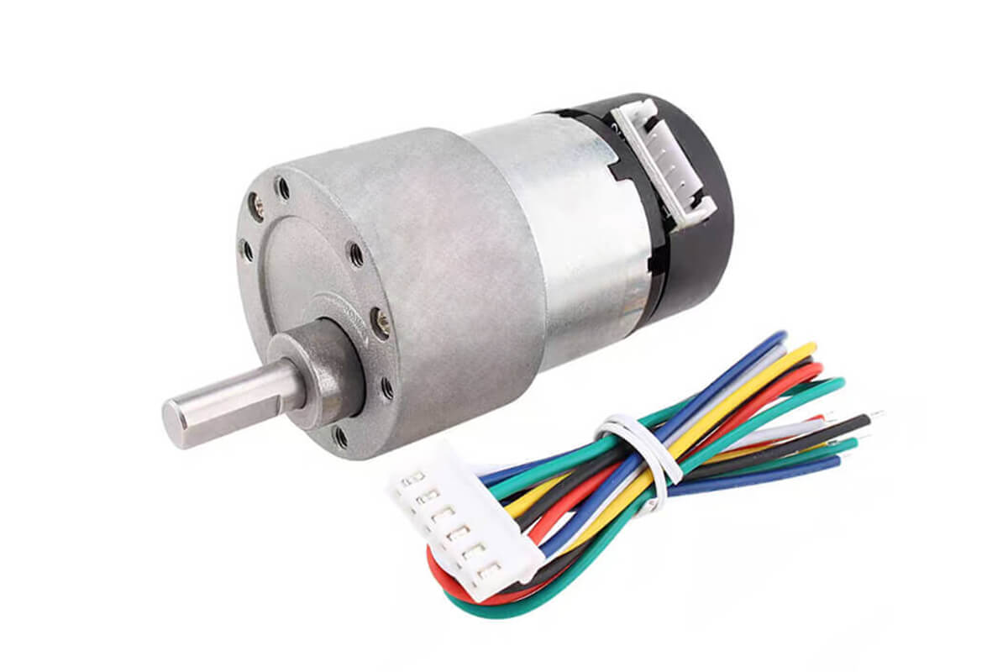
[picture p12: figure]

Figure 17: NHYTech GA37 520 DC motor [29].

5. Implementation

### 5.2.7. Infrared Sensing

The robot is equipped with infrared proximity sensors at the front-left and front-right directions using the Everlight Elec IR Receiver (IRM-56384) and the Infrared LED (IR204C-A), as shown in Fig 18.

These sensors detect obstacles by transmitting a modulated infrared signal and detecting its reflection.

(a) (b)

Figure 18: (a) IR204C-A infrared LED [31]; (b) IRM-56384 infrared reciever [32].

### 5.2.8. Ultrasonic Distance Sensor

The HC-SR04 is an ultrasonic distance sensor, shown in Fig. 19a, used for measuring the distance to an obstacle by sending an ultrasonic pulse and measuring the time it takes for the echo to return. It operates based on the principle of time-of-flight of sound waves, with a known speed of sound in air. The operation of the HC-SR04 ultrasonic sensor is discussed in detail in Section 8.

(a) (b)

Figure 19: (a) HC-SR04 ultrasonic distance sensor [30]; (b) Bluetooth module [33].

### 5.2.9. Bluetooth Module Integration

The BT16 Bluetooth UART Module was integrated to provided a robust wireless communication link between the user and the mobile base. The BT16 Bluetooth UART Module is a high-performance component based on the Airoha ABI 602 chipset, compliant with the Bluetooth 4.2 BLE standard. It interfaces with the microcontroller via UART, ensuring efficient bidirectional data transmission. The module supports GATT-based communication through an integrated transparent data transmission

service, enabling seamless and reliable Bluetooth connectivity.
A key feature of the BT16 module is its serial command mode, which allows direct configuration and control via UART commands. Users can modify essential parameters, such as the UUID, device name, and connection settings, facilitating flexible integration into various applications.

5. Implementation

Using this Bluetooth module, we can establish a wireless serial communication channel between a remote device (e.g., a smartphone or computer) and the Arduino Nano’s serial port. This enables real-

time transmission and reception of commands, allowing users to send movement instructions to the robot and receive telemetry data such as position, orientation, and sensor readings. This bidirectional communication ensures effective remote control and monitoring, making it suitable for applications requiring dynamic adjustments and feedback.

### 5.3. TeraRanger Multiflex

The TeraRanger Multiflex is a modular infrared laser Time-of-Flight (ToF) sensor array, as shown in Fig. 3. The system includes eight ToF sensors, a Multiflex Hub, and a circular 3D printed mount [18].

The TeraRanger Multiflex UART interface operates at 3.3 V output levels and is connected to the ESP32-S3-DevKitC-1 using the default UART configuration, as detailed in Table 1.

Table 1: UART Communication Configuration
Parameter | Value
Baud Rate | 115200 bit/s
Data Bits | 8
Parity | None
Stop Bits | 1

6. Sensor Fusion

## 6. Sensor Fusion

Complementary filtering, combined with Kalman filtering techniques, is utilised to estimate the state of pitch (or tilt) angle ψ as illustrated in Fig. 32.

### 6.1. Complementary Filter

The complementary filter is a simple yet effective method for sensor fusion [34] [35] [36]. It blends

high-frequency data from the gyroscope with low-frequency data from the accelerometer. The raw accelerometer readings from IMU can be used to estimate tilt angle ψacc using following equation, 1

ψacc = arctan

−Az q
A²

x + A²
y
- (10)

Where, Ax, Ay and Az are the raw acceleration data acquired from the IMU along x, y and z axes, respectively. Similarly, the raw gyroscope readings from the IMU can be used to estimate the angular veocity ψ˙
gyro,biased,
ψ˙

gyro,biased = ψ˙

gyro − ψ˙
bias | (11)

Where, ψ˙

gyro is the raw data from the gyroscope of the IMU and ψ˙ bias represents the bias of the gyroscope, which is constant for the IMU used in this project. The value for ψ˙
bias is calculated by
collecting multiple readings and averaging. If ∆t is the sample time and ψprev is the previous angle value then the estimate tilt angle using gyroscope values can be calculated as following,

ψgyro = ψprev + ψ˙
gyro,biased · ∆t | (12)

Then the final estimated pitch angle ψ is calculated as,

ψ = α · ψgyro + (1 − α) · ψacc | (13)

Where α is the filter coefficient. The value for filter coefficient through testing was to 0.9 which significantly reduces accelerometer noise while keep convergent time short. The results are shown in 20.

### 6.2. Extended Kalman Filter

Kalman filter was selected for this self-balancing robot mobile base because of its effectiveness in enhancing sensor fusion for precise state estimation and its capacity to reduce costs by effectively utilising lower-cost sensors [37] [38] [39].
The Kalman filter (KF) provides a more sophisticated approach, estimating the true state of the

system by minimizing the mean of the squared error. It involves prediction and update steps, and

1
arctan(y, x) =

arctan
y
x
if x > 0,
arctan
y
x
+ π if x < 0 and y ≥ 0,
arctan
y
x
− π if x < 0 and y < 0,
+

π
2

if x = 0 and y > 0,
−

π
2

if x = 0 and y < 0,
undefined | if x = 0 and y = 0.

6. Sensor Fusion

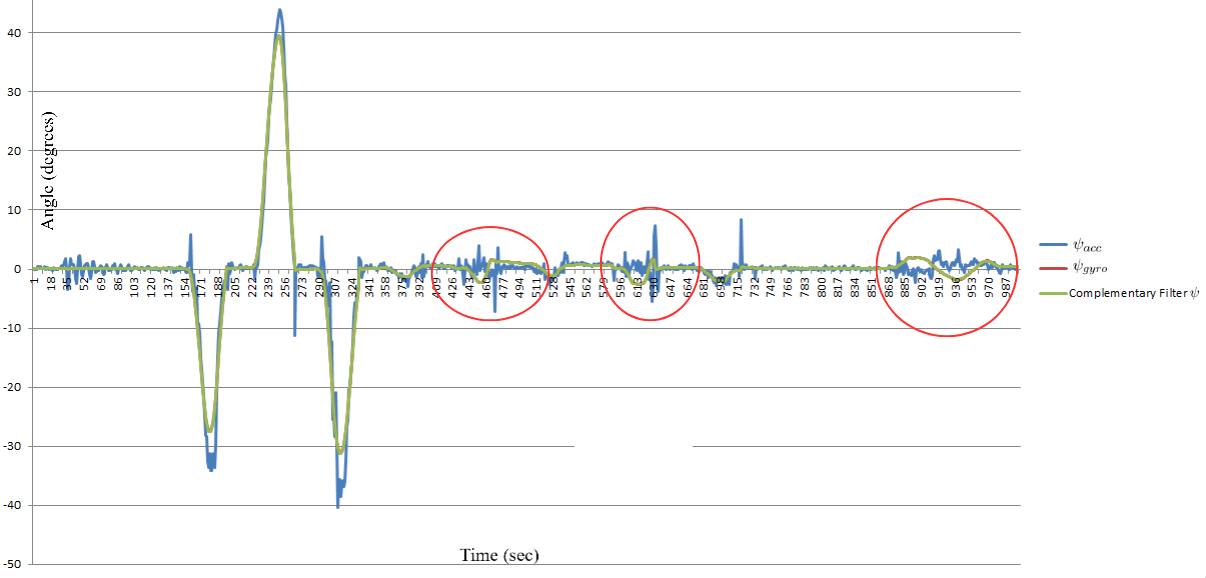
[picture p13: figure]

Figure 20: Pitch angle calculated using a complementary filter with α = 0.9. It can be observed that the high frequency accelerometer noise (circled in red) are filtered properly. And similarly the low frequency integration errors of the gyroscope (red) are removed over longer interval of time.

assumes that both the process and measurement models are linear. However, many real-world systems, such as robotic motion and sensor fusion, exhibit inherent non-linearities. When linearization is not feasible, the standard KF becomes inaccurate.
To address this limitation, the Extended Kalman Filter (EKF) extends the KF to non-linear systems

by employing a first-order Taylor series expansion. This method approximates the non-linear system dynamics and measurement models with locally linearized representations, allowing the filter to be applied in scenarios where exact linearization is not feasible. EKF maintains a Gaussian belief over the state, updating it through a prediction-correction cycle.

### 6.2.1. Extended Kalman Filter for Estimating Pitch Angle

The estimate of vertical angle ψ can be calculated based on previous angle ψprevious and angular velocity ψ˙
,

ψ = ψprevious + (ψ˙ − ψ˙
b) ∗ ∆t

Where the state vector can be defined as x(t) = " ψ
ψ˙
b
. Where ψ˙
b denotes the bias or drift error of the

gyroscope. Similarly, the measurement equation for is defined as,

y = ψ˙
gyro

Where, ψ˙
gyro is the pitch angular velocity measured by the gyroscope inside IMU. The derivation of equations for the Kalman filter is available in Appendix B.

6. Sensor Fusion

### 6.2.2. Predicted State Estimate

From Eq. 73, the discrete current state estimate xˆk|k−1 can be written as,

xˆk|k−1 = G xˆk−1|k−1 + H ψ˙
gyro,k

Where, xˆk−1|k−1

is a priori state estimate, and ψ˙ gyro,k is the angular velocity measured by the gyroscope at current step k. Also G is the state transition and is equal to " 1 −∆t

0 1 #
, and H is the control input

and is equal to "
∆t

0

Using above equation we can derive following discrete state equation,

ψk|k−1 = ψk−1|k−1 + ∆t(ψ˙ − ψ˙
b)k−1|k−1

Where, ψk|k−1 and ψk−1|k−1

is a priori and previous state estimate, respectively, of the vertical angle of the robot. And the gyroscope bias ψ˙

b stay constant (e.g. ψ˙

b,k|k−1 = ψ˙
b,k−1|k−1

).

### 6.2.3. Predicted Error Covariance

From Eq. 79, the priori measurement covariance matrix Pk|k−1 was derived to be,

Pk|k−1 =

"
P00 | P01
P10 | P11#

k|k−1

=

"
P

−
00 + [(Qψ + ∆tP11 − P

−
01 − P

−
10) ∗ ∆t] P

−
01 − (P

−
11 ∗ ∆t)

P

−
10 − (P

−
11 ∗ ∆t) | P

−
| 11 + (Qψ˙
b

∗ ∆t)

Where the negative sign (e.g. " - ") on top of P

−
00, P

−
10, P

−
11 and P

−
01 represents that these parameters were calculated using previous step k − 1 values. And Qψ is the accelerometer process noise variance

and Qψ˙
b

is the process noise variance of gyroscope bias. As suggested in [40], the value of Qψ can be

set to 0.001, while Qψ˙
b

is recommended to be set at 0.003 for most IMUs.

### 6.2.4. Innovation Residual

From Eq. 78, the innovation residual y˜k can be calculated as,

y˜k = zk − ψk|k−1

Where, zk is the measurement made at time step k by combining the values of ψacce and ψgyro using Eq. 13.

### 6.2.5. Innovation Covariance

From Eq. 79, the innovation covariance Sk can be calculated as,

Sk = P00,k|k−1 + Rψ

Where, Rψ is the measurement covariance and is simply equal to the variance of IMU sensor var(v) (see Eq. 72). According to the datasheet for the MPU6050, this variance is approximately 0.003 [24].

6. Sensor Fusion

### 6.2.6. Optimal Kalman Gain

From Eq. 81, the optimal Kalman gain Kk can be calculated as,

Kk =

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
### 6.2.7. Corrected State Estimate

From Eq. 82, the updated (or posteriori) state estimate xˆk|k can be calculated as,

xˆk|k = ˆxk|k−1 + Kk y˜k

### 6.2.8. Corrected Estimate Covariance

From Eq. 83, the posteriori measurement covariance matrix Pk|k ,

Pk|k =

"
P00 − K0 · P00 | P01 − K0 · P01
P10 − K1 · P00 | P11 − K1 · P01#
(14)

### 6.3. Software Implementation of EKF

For the implementation of the EKF, we utilized the Kalman filter library developed by Kristian Lauszus [40]. This library was modified in accordance with the GNU General Public License to meet

the specific requirements of our project. The pseudocode for the filtering process is presented in Algorithm 2.

6. Sensor Fusion

Algorithm 2 Kalman Filter Angle Estimation
1: procedure EstimateAngle(measuredAngle, measuredGyro)
Prediction Step:
2: | angle ← angle + (measuredGyro − bias) · ∆t | ▷ Update angle based on gyroscope data
3: | y ← measuredAngle − angle | ▷ Calculate measurement residual
| Covariance Matrix Time Update:
4: | P00 ← P00 + (P11 · ∆t + Qangle − P01 − P10) · ∆t | ▷ Update covariance for angle
5: | P01 ← P01 − P11 · ∆t | ▷ Update cross-covariance
6: | P10 ← P10 − P11 · ∆t | ▷ Update cross-covariance
7: | P11 ← P11 + Qgyro · ∆t | ▷ Update covariance for gyro
| Compute Kalman Gain:
8: | S ← Rangle + P00 | ▷ Calculate innovation covariance
9: | K0 ← P00 S | ▷ Calculate Kalman gain for angle
10: | K1 ← P10 S | ▷ Calculate Kalman gain for bias
| Correct the Angle and Bias:
11: | angle ← angle + K0 · y | ▷ Update angle estimate
12: | bias ← bias + K1 · y | ▷ Update bias estimate
| Update the Covariance Matrix:
13: | P00 ← P00 − K0 · P00 | ▷ Update covariance for angle
14: | P01 ← P01 − K0 · P01 | ▷ Update cross-covariance
15: | P10 ← P10 − K1 · P00 | ▷ Update cross-covariance
16: | P11 ← P11 − K1 · P01 | ▷ Update covariance for gyro
17: | return angle | ▷ Return the estimated angle
18: end procedure

7. Motor Control

## 7. Motor Control

The system employs a Proportional-Integral-Derivative (PID) control loop to achieve real-time balance

and motion control of the robot. This control architecture ensures stability by continuously monitoring and adjusting the robot’s state using feedback from multiple sensors [41]. Key inputs to the control loop include: the robot’s pitch angle ψ (as illustrated in Fig. 32), gyroscope data, and motor encoder

values, which provide critical information on orientation, angular velocities, and position.

- Pitch angle: Provides information about the robot’s tilt relative to the vertical y-axis.
- Gyroscope data: Supplies angular velocity measurements for dynamic stabilization.
- Motor encoder values: Tracks relative wheel position and velocity for precise motion control.

The control algorithm computes outputs for pitch, yaw, and position at regular intervals, generating pulse-width-modulation (PWM) signals to adjust motor speeds via the motor driver. A control block

diagram for pitch angle ψ PID controller is shown in Fig. 21.

Figure 21: Block diagram for pitch angle ψ control.

Similarly, a PID controller is utilized to manage both the yaw angle and distance. To prioritize system stability, the pitch angle is updated at a higher frequency (e.g., every control cycle), while the yaw angle and position control outputs are updated less frequently (e.g., every eighth cycle). This

strategy optimizes resource utilization while ensuring robust performance.

### 7.1. PID Controller

The PID controller generates a control signal u(t) based on the error signal e(t), which is the difference

between the desired set-point and the measured process variable. The control signal is computed as follows,

u(t) = Kpe(t) + Ki

Z t

0

e(τ )dτ + Kd

d
dte(t) | (15)

Where:

- u(t): Control signal applied to the system.
- e(t): Error signal, representing the deviation from the setpoint.
- Kp: Proportional gain, which responds to the current error.
- Ki

: Integral gain, which addresses accumulated past errors.

7. Motor Control
- Kd: Derivative gain, which predicts future error trends based on the rate of change.

For digital implementation, the continuous-time PID equation is discretized to suit microcontroller-based systems. The discrete-time PID control signal u[n] is calculated as:

u[n] = Kp e[n] + Ki Ts

Xn

k=0

e[k] + Kd

e[n] − e[n − 1]
Ts

(16)

Where, Ts is sampling period, representing the time interval between consecutive control updates, e[n] error signal at the n-th sampling instant and u[n] control signal at the n-th sampling instant.

This formulation ensures compatibility with real-time embedded systems while maintaining control precision.

### 7.2. PID Tuning Methodology

The Ziegler-Nichols method is a widely used and systematic approach for tuning PID controllers. It provides a reliable framework for determining initial controller parameters, which can then be fine-tuned for optimal performance. The method involves inducing controlled oscillations in the system to identify critical parameters, which are then used to calculate the proportional, integral, and derivative gains.

### 7.2.1. Ziegler-Nichols Method

The Ziegler-Nichols tuning procedure consists of the following steps:

1. Initialize Parameters: Set the integral gain Ki and derivative gain Kd to zero, leaving only the proportional gain Kp active.
2. Induce Oscillations: Gradually increase Kp until the system exhibits sustained oscillations. At this point, the system is at the threshold of stability, and the proportional gain is referred to as the ultimate gain Ku. The period of these oscillations is denoted as Tu.
3. Record Critical Values: Note the values of Ku and Tu, as they are essential for calculating the final PID parameters.
4. Calculate PID Gains: Using the recorded values, compute the PID parameters as follows:

Kp = 0.6Ku

Ti = 0.5Tu

Td = 0.125Tu

(17)

Here, Ti and Td represent the integral and derivative time constants, respectively. These values are then used to determine the integral and derivative gains:

Ki =

Kp
Ti
and Kd = Kp · Td. | (18)

This method provides a robust starting point for achieving stable control. However, it is important to note that the Ziegler-Nichols method may require additional fine-tuning to account for system-specific

7. Motor Control

dynamics and performance requirements. The calculated parameters serve as an initial baseline, which can be further optimized through iterative testing and adjustment.

### 7.2.2. Practical Tuning Guidelines

In addition to the Ziegler-Nichols method, practical tuning guidelines were applied to refine the controller performance:

- Start with a small proportional gain Kp (e.g. Kp = 10) to avoid instability.
- Introduce the derivative term Kd to dampen oscillations, typically setting Kd = 0.1Kp.
- Fine-tune Kp, Ki

, and Kd iteratively to achieve optimal stability and responsiveness.

### 7.3. Multi-rate PID Control

To optimize system performance and resource utilization, the control loop employs a Multi-rate PID strategy:

- Pitch Control: Updated at the highest frequency (e.g., every control cycle) to ensure rapid

response to changes in the robot’s tilt and maintain balance.

- Yaw and Position Control: Updated at a lower frequency (e.g., every 8th cycle) to reduce

computational load while still providing adequate motion control.

This approach prioritizes critical tasks (e.g., maintaining balance) while efficiently managing system

resources, ensuring robust and stable operation. A simplified flow diagram for a Multi-rate PID

controller is shown in Fig. 22.

### 7.3.1. Pitch Control

The pitch control loop ensures the robot maintains its upright position. The primary objective of the pitch controller is to minimize the deviation of the robot’s pitch angle ψ from a set-point. The pitch control output is calculated using the PD algorithm, where the error is the difference between the current pitch angle and the desired pitch angle. However, the integration component of the PD controller is unnecessary due to the system’s inherent instability. Instead, a proportional and derivative (PD) control strategy is more appropriate. The equation for the PD controller is as follows,

τψ,pd = Kpψ(ψdesired − ψmeasured) + Kdψ

d
dt(ψdesired − ψmeasured) | (19)

Where, τψ,pd is the pitch control output, ψdesired is the desired pitch angle and ψmeasured is the estimated pitch angle obtained using the Extended Kalman Filter, as calculated in Eq. 82.

7. Motor Control

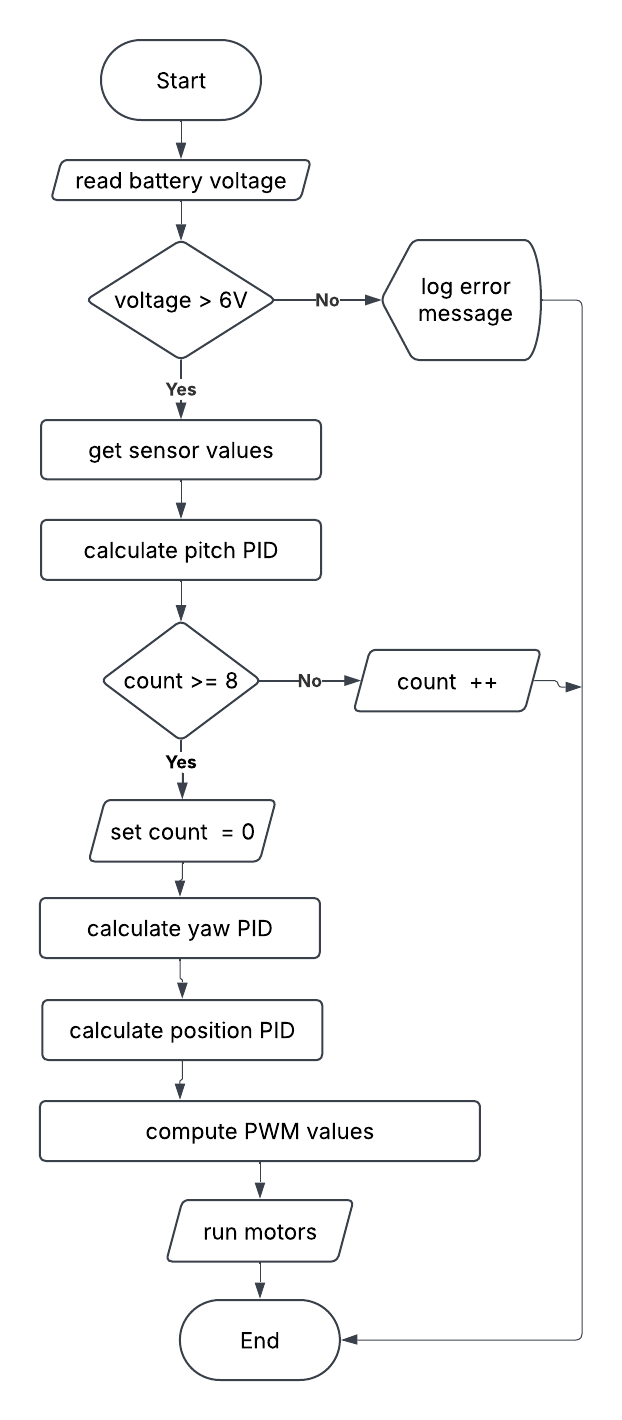
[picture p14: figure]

Figure 22: A simplified flow diagram of the multi-rate PID control loop used.

7. Motor Control

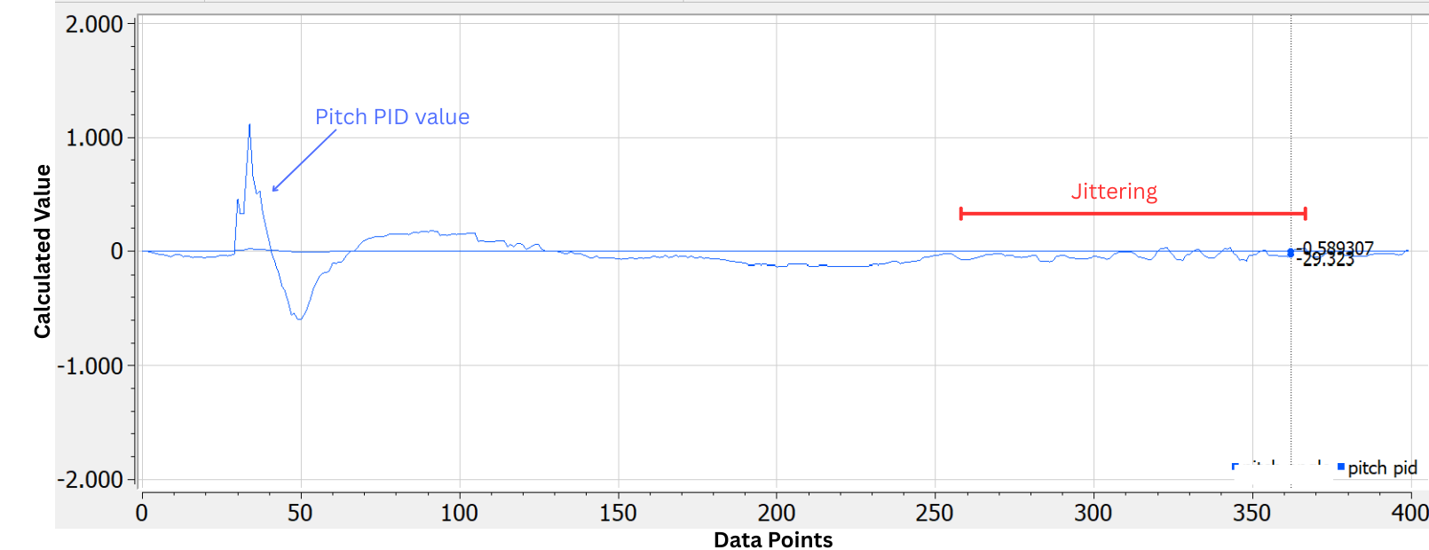
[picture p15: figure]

Figure 23: Output values calculated by the pitch angle PD controller at Kpψ = 55 and Kdψ = 1.25. The data was recorded at baud rate of 115200.

The output values calculated by the pitch angle PD controller, shown in Fig. 23, indicates that system quickly reaches the desired vertical position. However, once stability is achieved, the system begins to exhibit jitter—characterised by small, rapid fluctuations in the control output—particularly evident in the PD output between data points 300 and 400 in Fig. 23. This jitter is a result of the high sensitivity of the derivative gain (Kdψ) to fluctuations in the gyroscope readings (ψ˙). While reducing

Kdψ mitigates the jitter, it also diminishes the system’s ability to dampen oscillations, leading to excessive overshoot and potential instability, as shown in Fig. 24.

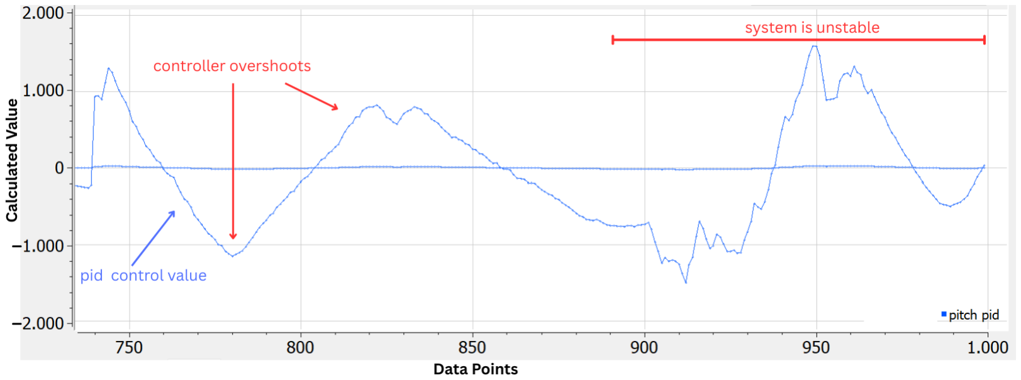
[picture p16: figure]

Figure 24: Output values calculated by the pitch angle PD controller at Kpψ = 55 and Kdψ = 0.75. Data recorded at baud rate of 115200.

It can be observed from Fig. 24 that the system overshoots primarily due to low value of Kd. This insufficient derivative gain leads to excessive oscillations, ultimately resulting in instability, as evidenced by the data points from 900 onwards. To address this issue, an adaptive derivative gain approach is implemented, where Kdψ is adjusted dynamically based on the pitch angle of the robot. When the absolute pitch angle ψ exceeds a predefined threshold, a higher derivative gain is used to provide stronger correction, while a lower gain is applied for small angles to minimize jitter. The

7. Motor Control

algorithm used for implementing adaptive derivative gain is as follows,

Algorithm 3 Adaptive Derivative Gain Logic
1: if pitch_angle > 8 degrees then | ▷ predefined small angle threshold
2: | kd ← 1.25 | ▷ for large angles
3: else
4: | kd ← 0.75 | ▷ for small angles
5: end if

This adaptive control strategy effectively stabilises the system, resulting in reduced oscillations and the elimination of jitter, as shown Fig. 25.

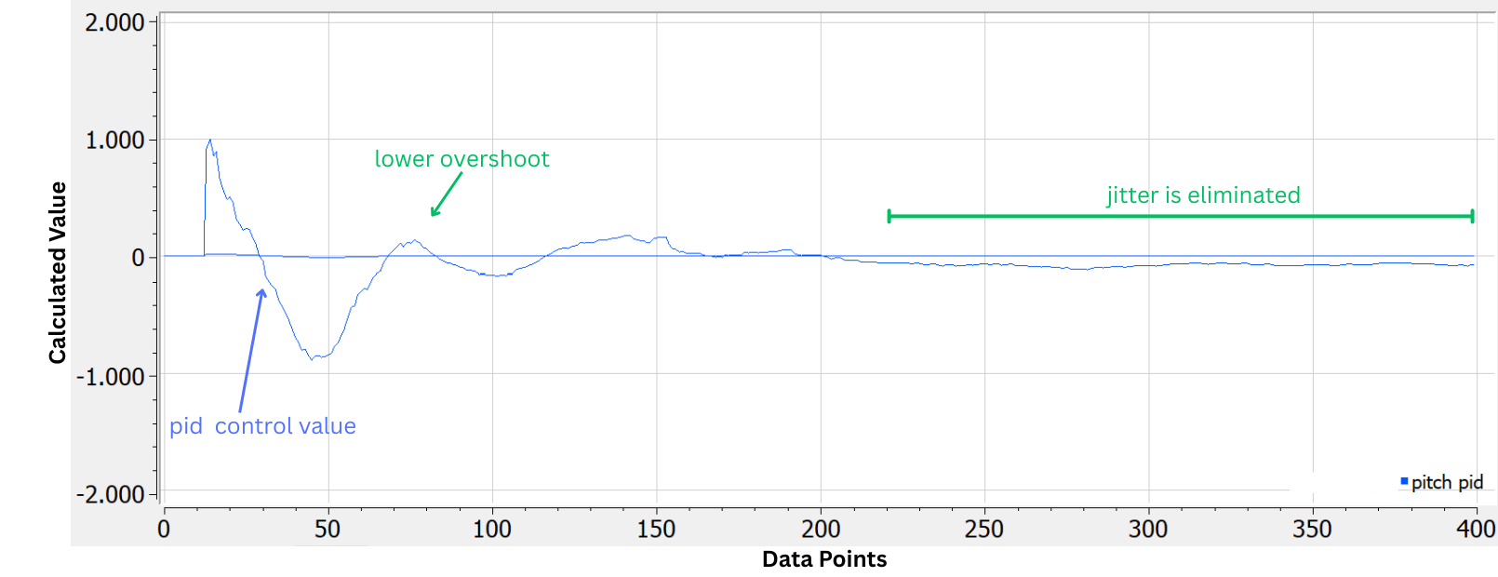
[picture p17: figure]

Figure 25: Output values calculated by the pitch angle PD controller with an adaptive derivative gain at Kpψ = 55 and Kdψ = 0.75 ∼ 1.25. The data was recorded at baud rate of 115200.

### 7.3.2. Yaw Control

Yaw control is responsible for controlling the robot’s rotational movement around its vertical y-axis shown in Fig. 32. After testing, it was determined that the steady-state error is minimal, indicating that a PD controller is adequate for effective control. The yaw PD controller computes the control output based on the robot’s angular velocity, which is measured by the gyroscope along the y-axis.

τϕ,pd = Kpϕ(ϕdesired − ϕ) + Kdϕ

d
dt(ϕdesired − ϕ) | (20)

Where, τϕ,pd is the yaw control output, ϕdesired is the desired yaw angle, and ϕ is the estimate of angle of rotation about y-axis. The yaw angle ϕ can be calculated based on previous yaw angle ϕprevious and angular velocity ϕ˙
gyro measured by the gyroscope using following equation,

ϕ = ϕprevious + (ϕ˙

gyro − ϕ˙
b) ∗ ∆t

Where ϕ˙
b denotes the bias or drift error of the gyroscope. The yaw angle is measured relative to the initial yaw angle when the system is initiated, indicating that it is not aligned with the x-axis shown in Fig. 32.

7. Motor Control

The yaw control adjusts the motor speeds to achieve the desired angle, ensuring the robot maintains a stable heading. Fig. 26 illustrates the system’s response with Kpϕ = 2.5 and Kdϕ = 0.5 when transitioning from an initial angle of −20 deg to final angle of +20 deg.

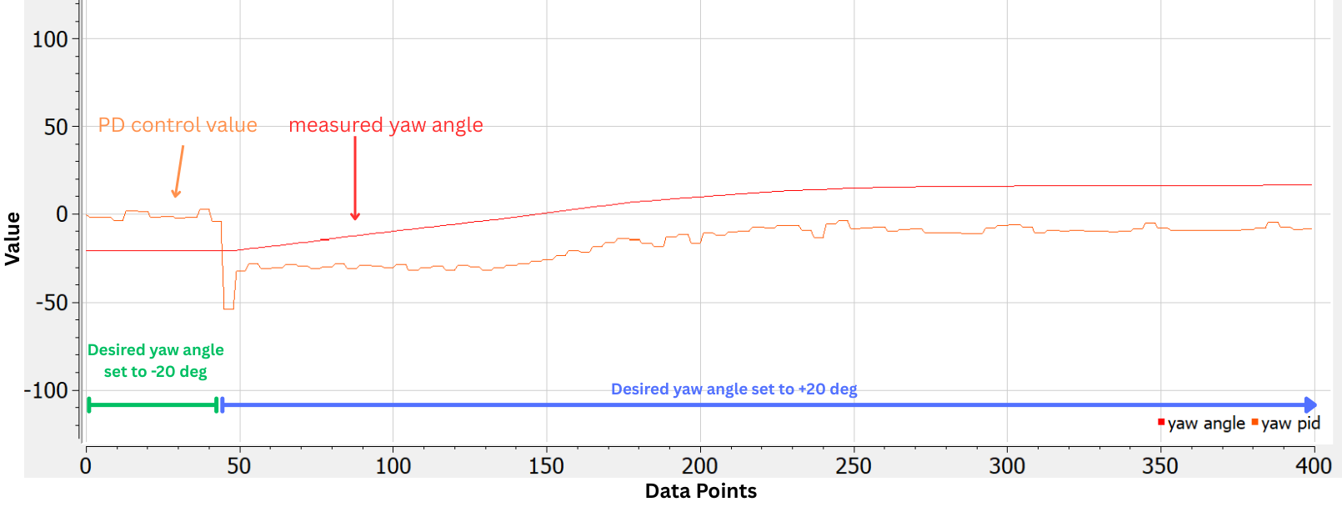
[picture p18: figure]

Figure 26: Yaw angle control system response at Kp = 2.5 and Kd = 0.5 for angle varying from −20 deg to +20 deg. The data was recorded at baud rate of 115200.

As shown in the Fig. 26, the robot moves to the desired yaw angle changes smoothly without any

overshoot.

### 7.3.3. Position Control

Due to integration errors associated with estimating distance from acceleration values obtained from the MPU6050, the encoder values from the Hall-effect encoders in the DC drive motors were utilized for distance estimation along the x-axis shown in Fig. 32. The raw data obtained from encoders is processed using a Weighted Moving Average (WMA) filter to estimate the distance.
The encoder pulses are counted using an Interrupt Service Routine (ISR)—a specialized piece of

code that executes in response to an interrupt signal, allowing for efficient handling of asynchronous events—triggered by changes on the encoder signal pins, as shown in Algorithm 4. After each control cycle the encoder counts are accumulated while taking into account the direction of the motors using U pdateDistance function as shown in Algorithm 5. To further enhance the accuracy of position estimation, a Weighted Moving Average (WMA) filter is applied to reduce noise, as shown in

Algorithm 5. The filtered encoder pulses ωfiltered is calculated using the formula:

ωfiltered = α · ωprev + (1 − α) · ωraw | (21)

Where, ωprev is the previously filtered pulses, ωraw is the newly computed pulses from encoder readings and α is the weighting factor. In this project α = 0.7 was selected after testing. The implementation of the WMA filter is also shown in Algorithm 5, where constant the conversion factor for translating encoder pulses into distance was determined to be approximately 0.03125 centimetres per encoder pulse.
Position control is implemented to ensure the robot moves smoothly and accurately to the desired location. The encoder feedback from the left and right wheels is used to calculate the robot’s

7. Motor Control

Algorithm 4 Interrupt Handlers for Encoder Counts
1: Attach interrupt on edge change of LEF T_ENCODER_P IN to LeftEncoderISR
2: Attach interrupt on edge change of RIGHT_ENCODER_P IN to RightEncoderISR
3: procedure LeftEncoderISR
4: | L_Count ← L_Count + 1 | ▷ Increment left encoder count
5: end procedure
6: procedure RightEncoderISR
7: | R_Count ← R_Count + 1 | ▷ Increment right encoder count
8: end procedure

Algorithm 5 Update Total Distance
1: procedure UpdateDistance
2: | if Left motor moving forward then
3: | L_T otal ← L_T otal + L_Count
4: | else
5: | L_T otal ← L_T otal − L_Count
6: | end if
7: | if Right motor moving forward then
8: | R_T otal ← R_T otal + R_Count
9: | else
10: | R_T otal ← R_T otal − R_Count
11: | end if
12: | L_T otalf iltered ← (L_T otalf iltered,old × 0.7) + (L_T otal × 0.3)
13: | L_T otalf iltered,old ← L_T otalf iltered
14: | L_P osition ← L_P osition + L_T otalf iltered × CM_P ER_ENCODER_P ULSES
15: | R_T otalf iltered ← (R_T otalf iltered,old × 0.7) + (R_T otal × 0.3)
16: | R_T otalf iltered,old ← R_T otalf iltered
17: | R_P osition ← R_P osition + R_T otalf iltered × CM_P ER_ENCODER_P ULSES
18: end procedure

displacement and speed. The position PD controller adjusts the motor speeds to minimize the error in position. As shown in the Fig. 27, the robot moves to the desired position smoothly and without

any overshoot.

τx,pd = Kpx(xdesired − xmeasured) + Kdx

d
dt(xdesired − xmeasured) | (22)

Where, τx,pd is the position control output, xdesired is the desired position and xmeasured is the measured position. Fig. 27 presents the system’s response when Kpx = 0.26 and Kdx = 20 when moving from relative distance of −600 mm to +300 mm. As shown in the Fig. 27, the robot moves to the desired

position smoothly and without any overshoot.

### 7.3.4. Combining Control Outputs

The final motor control is achieved by combining the outputs from all three PD controllers. The outputs from the pitch, yaw, and position PD controllers are used to calculate the motor speeds, which determine the robot’s motion. Specifically, the following equations are used to compute the

7. Motor Control

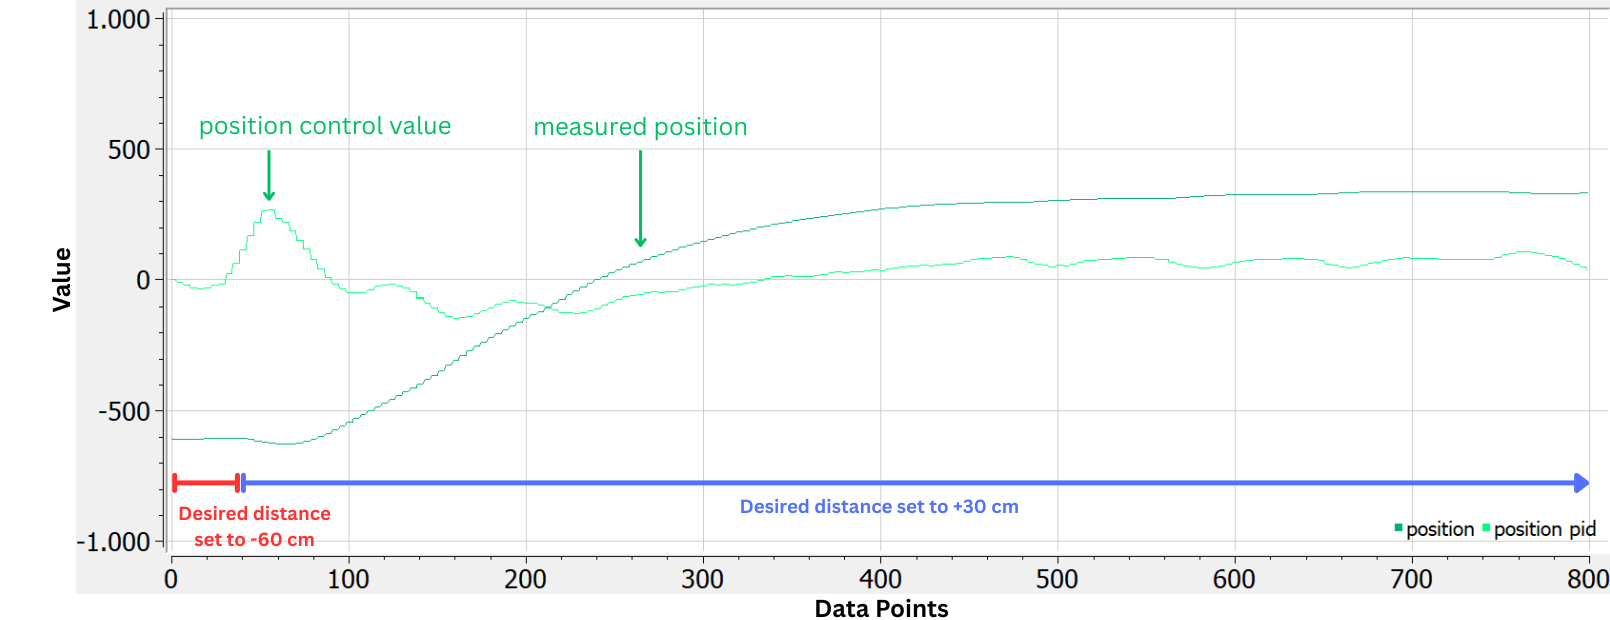
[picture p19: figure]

Figure 27: Position control system response with Kpx = 0.26 and Kdx = 20 for a displacement of −600 mm to +300 mm. Data recorded at baud rate of 115200.

Pulse-Width-Modulation (PWM) values for the left motor τlef t,motor and right motor τright,motor,

τlef t,motor = τθ,pd − τϕ,pd − τx,pd | (23)
τright,motor = τθ,pd + τϕ,pd − τx,pd | (24)

The PWM values +255 represents maximum forward speed, -255 represents maximum reverse, and 0 represents stationary state. The PWM values are constrained between -255 and +255 because a 8-bit timer is used by Arduino Nano to generate the PWM signal [21]. The computed PWM are

transmitted to the motor drivers, which adjust the robot’s movement and balance in real time. This closed-loop control mechanism ensures precise and stable operation by continuously refining motor outputs based on sensor feedback. A simplified diagram of the motor control loop is illustrated in

Fig. 28.

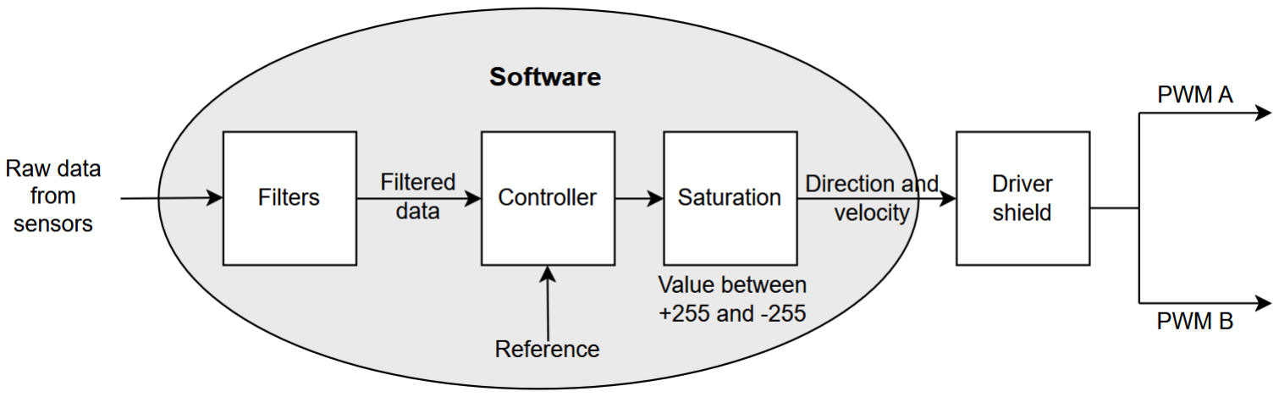
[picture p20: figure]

Figure 28: A simplified diagram of the motor control loop [35].

8. Front Obstacle Detection

## 8. Front Obstacle Detection

To robustly detect obstacles in its forward path, the robot employs a combination of an ultrasonic distance-measuring sensor and two infrared (IR) proximity sensors.

### 8.1. Operation of Ultrasonic sensor

The HC-SR04 ultrasonic module used in this project comprises two key components: a transmitter that emits high-frequency ultrasonic pulses and a receiver that detects the reflected pulses after they bounce off an obstacle. The distance to the obstacle is calculated by measuring the time delay between the transmission of the ultrasonic pulse and its reception. The HC-SR04 ultrasonic has a measuring range of 2cm – 400 cm (1" - 13ft) within a 30 degree cone [30]. The formula used to compute the

distance is as follows:
d =

t × v
2

(25)

Where d is the measured distance to the obstacle, t is the time delay between transmission and reception, and v is the speed of sound in air, which is approximately 340.29 m/s at room temperature (e.g. 20°C). Based on the datasheet [30], an operating frequency of 20 Hz is selected for distance

measurements.

### 8.1.1. Sound Signal Transmission

The HC-SR04 requires control signals to be sent from a microcontroller, A short trigger pulse (at least 10 µs) is sent to the TRIG pin. The following algorithm initiates distance measurement using the HC-

SR04 ultrasonic sensor by transmitting a 20Hz acoustic signal, which corresponds to a measurement interval of 50 ms. This means that the sensor can take a new distance measurement every 50 ms. The system periodically initiates a distance measurement by sending a trigger pulse to the ultrasonic sensor, as shown in Algorithm 6.

Algorithm 6 Start Ultrasonic Distance Measurement

1: procedure StartUltrasonicMeasurement
2: | if current time − previousT riggerT ime > T RIGGER_DELAY then
3: | Set measurementFlag ← SEND
4: | previousT riggerT ime ← current time
5: | Attach interrupt on rising edge of ECHO_P IN to HandleUltrasonicInterrupt
6: | Set T RIG_P IN to LOW
7: | Set T RIG_P IN to HIGH
8: | Wait for 10 µ s
9: | Set T RIG_P IN back to LOW
10: | end if
11: end procedure

Algorithm Explanation:

- The function StartUltrasonicMeasurement checks if the time elapsed since the last distance measurement exceeds the defined TRIGGER_DELAY of 50 ms. This ensures that measurements are taken at regular intervals, preventing overlap and ensuring accurate readings.

8. Front Obstacle Detection
- A global flag measurementFlag is set to SEND, indicating that the trigger pulse is sent.
- Then attaches an interrupt to the ECHO_PIN pin, allowing the microcontroller to detect when the echo signal is received.
- The TRIG_PIN pin is first set to LOW to prepare for the trigger pulse, then set to HIGH for 10 µs to send the trigger pulse, and finally set back to LOW to reset the trigger.

This setup enables precise distance measurement by capturing the time delay between sending the ultrasonic pulse and receiving the echo, allowing for accurate distance calculations.

### 8.1.2. Sound Signal Reception

The HC-SR04 ultrasonic sensor responds to the transmitted acoustic signal by generating a high signal on the ECHO pin. The duration of this high signal corresponds to the time taken for the sound waves to travel to an obstacle and back. To accurately measure this duration and calculate the distance, an Interrupt Service Routine (ISR) is employed. The Algorithm 7 outlines the steps taken in the ISR to

measure the distance using the received acoustic signal,

Algorithm 7 Ultrasonic Echo Interrupt Handler

1: procedure HandleUltrasonicInterrupt
2: | if usonicMeasureFlag = SEND then
3: | usonicMeasureP revT ime ← current time | ▷ Rising edge capture
4: | Reconfig. interrupt on falling edge of ECHO_P IN to HandleUltrasonicInterrupt
5: | usonicMeasureFlag ← RECEIV ED
6: | else if usonicMeasureFlag = RECEIV ED then
7: | ∆t ← (current time − usonicMeasureP revT ime)
8: | usonicDistanceV alue ← (∆t × 0.34029) | ▷ Convert duration to cm
9: | usonicMeasureFlag ← IDLE | ▷ Reset state machine
10: | end if
11: end procedure

Algorithm Explanation:

1. Rising Edge Detection:
- When the ECHO signal transitions to a high state (RISING edge), the current timestamp is

recorded as usonicMeasurePrevTime.

- The interrupt is then reconfigured to detect the falling edge of the ECHO signal, which indicates the end of the echo.
- The flag usonicMeasureFlag is updated to RECEIVED to indicate that the echo signal is being processed.
2. Falling Edge Detection:
- Upon detecting the falling edge, the elapsed time (∆t) is calculated as the difference between

the current time and the previously recorded timestamp.

8. Front Obstacle Detection
- The distance to the obstacle is then calculated using the formula:

d =

∆t × v
2

(26)

Where v is the speed of sound in air, approximately 340.29 m/s.

- Finally, the flag usonicMeasureFlag is reset to IDLE to prepare the system for the next measurement cycle.

In summary, the ISR efficiently captures the duration of the echo signal by detecting both the rising and falling edges of the ECHO pin. This allows for accurate distance calculations based on the time taken for the sound waves to travel to the obstacle and back, ensuring reliable performance of the ultrasonic measurement system.

### 8.2. Infrared Sensing

Infrared (IR) sensors are employed for proximity-based obstacle detection. The system periodically

emits modulated infrared pulses and processes the received reflections to infer the presence of nearby obstacles.

### 8.2.1. IR Signal Emission

The IR204C-A infrared LED generates a 38 kHz square wave signal by toggling the output pin at 18 µs intervals, comprising 9 µs LOW and 9 µs HIGH phases. This emitted signal is detected by the IR receiver IRM-56384, which is tuned to the frequency of 38 kHz [32]. Algorithm 8 illustrates the

signal generation.

Algorithm 8 Transmit 38 kHz IR Pulse
1: procedure Send38kHzPulse(ir_pin)
2: | for i ← 1 to 39 do
3: | Set digital output ir_pin to LOW
4: | Wait for 9 µs
5: | Set digital output ir_pin to HIGH
6: | Wait for 9 µs
7: | end for
8: end procedure

### 8.2.2. IR Signal Reception

The IR receiver IRM-56384 detect modulated infrared signals transmitted by the IR204C-A infrared LED. The receiving mechanism relies on edge-triggered interrupts to accurately count the number of incoming IR pulses. Each IR receiver (left and right) uses an interrupt service routine (ISR) to toggle

between detecting rising and falling edges of the IR signal. On the rising edge, a flag is set to indicate that a new pulse may have begun, while on the falling edge, the pulse is confirmed and counted. Algorithm 9 summarizes the interrupt-driven pulse counting strategy used by the IR receivers.

8. Front Obstacle Detection

Algorithm 9 IR Signal Pulse Counting Using Edge Detection 1: procedure IRLeftReceive
2: | if irLef tReceiveFlag = false then
3: | irLef tReceiveFlag ← true
4: | Enable interrupt on RISING edge of LEF T_RECEIV E_P IN
5: | else
6: | Increment irLef tP ulseCount
7: | irLef tReceiveFlag ← false
8: | Enable interrupt on FALLING edge of LEF T_RECEIV E_P IN
9: | end if
10: end procedure
11: procedure IRRightReceive
12: | if irRightReceiveFlag = false then
13: | irRightReceiveFlag ← true
14: | Enable interrupt on RISING edge of RIGHT_RECEIV E_P IN
15: | else
16: | Increment irRightP ulseCount
17: | irRightReceiveFlag ← false
18: | Enable interrupt on FALLING edge of RIGHT_RECEIV E_P IN
19: | end if
20: end procedure

Algorithm Explanation:

- Each IR receiver function operates as an interrupt service routine triggered by a signal edge.
- On detecting a rising edge, the corresponding flag is set and the interrupt is immediately reconfigured to detect a falling edge.
- On the falling edge, a full pulse is considered received, so the pulse counter is incremented. The flag is cleared, and the interrupt is again set to detect a rising edge.
- This alternating edge detection mechanism ensures robust counting of complete IR pulses and minimizes missed detections caused by noise or signal jitter.

This interrupt-based approach allows the system to efficiently track IR signal activity with minimal processing overhead, enabling real-time response to environmental cues and communication signals.

### 8.2.3. Binary Filter:

To ensure robust and noise-resilient obstacle detection, a binary filtering technique is applied to the IR pulse counts. The system employs a sliding window mechanism that evaluates whether an obstacle is present by analyzing a sequence of binary decisions over time. This approach reduces false positives caused by transient disturbances or environmental noise.
At regular intervals, the IR sensors are activated to transmit a modulated 38 kHz signal. The number of pulses received is evaluated, and if the pulse count exceeds a predefined threshold, the result is considered as a binary “1” (obstacle detected); otherwise, a binary “0” is recorded. These

binary decisions are then passed into a circular sliding window, which maintains a running count of obstacle-positive entries. If the number of positive entries within the window exceeds a defined

8. Front Obstacle Detection

threshold, the presence of an obstacle is confirmed. The complete algorithm for this filtering method is outlined in Algorithm 10.

Algorithm 10 Binary Filter for Obstacle Detection
1: procedure CheckIRObstacle
2: | if current time − irSendT ime > IR_P ULSE_DELAY _MS then
3: | Send 38kHz IR pulse from IR_SEND_P IN
4: | irSendT ime ← current time
5: | end if
6: | ProcessLeftIRSensor
7: | ProcessRightIRSensor
8: end procedure
9: procedure ProcessLeftIRSensor
10: | if current time − irLef tCountT ime > IR_COUNT_DELAY _MS then
11: | obstacleDetected ← (irLef tP ulseCount ≥ 3)
12: | UpdateSlidingWindow(obstacleDetected, | irLef tHistory, | irLef tIndex,
| irLef tRunningCount)
13: | irLef tIsObstacle ← (irLef tRunningCount ≥ 5)
14: | Reset irLef tP ulseCount and update irLef tCountT ime
15: | end if
16: end procedure
17: procedure ProcessRightIRSensor
18: | if current time − irRightCountT ime > IR_COUNT_DELAY _MS then
19: | obstacleDetected ← (irRightP ulseCount ≥ 3)
20: | UpdateSlidingWindow(obstacleDetected, | irRightHistory, | irRightIndex,
| irRightRunningCount)
21: | irRightIsObstacle ← (irRightRunningCount ≥ 5)
22: | Reset irRightP ulseCount and update irRightCountT ime
23: | end if
24: end procedure
25: procedure UpdateSlidingWindow(value, history, index, runningCount)
26: | runningCount ← runningCount − history[index] + value
27: | history[index] ← value
28: | index ← (index + 1) mod SLIDING_W INDOW_SIZE
29: end procedure

Algorithm Explanation:

- The function CheckIRObstacle regularly sends IR pulses and then calls individual sensor processing functions for left and right IR receivers.
- In ProcessLeftIRSensor and ProcessRightIRSensor, the system checks if the IR pulse count over a sampling period exceeds a threshold (e.g., 3 pulses). If so, it considers that a binary

detection of an obstacle has occurred.

- A binary value (1 for obstacle, 0 otherwise) is inserted into a fixed-size sliding window using the

UpdateSlidingWindow function.

- The running count in the window is updated in constant time by subtracting the value being replaced and adding the new value.

8. Front Obstacle Detection
- If enough detections (e.g., 5) occur within the window, an obstacle is confirmed on the respective

side.

This binary filtering method offers computational efficiency and robust noise immunity, making it well-suited for real-time embedded systems where sensor signals may fluctuate due to ambient interference or hardware limitations.

### 8.3. Obstacle Decision Logic

To reliably determine the presence of a front obstacle, the system fuses measurements from the HC-SR04 ultrasonic sensor and the binary-filtered outputs of both IR sensors. An obstacle is confirmed if

either:

- The ultrasonic distance d falls below a predefined threshold dthresh (e.g., 20 cm), and
- The binary filter outputs from both IR sensors indicate persistent obstacle presence.

This decision logic is summarized in Algorithm 11. It enhances detection robustness by leveraging the strengths of both sensing modalities: the ultrasonic sensor’s range accuracy and the IR sensors’ fast response to proximity.

Algorithm 11 Front Obstacle Detection Logic

1: procedure IsFrontObstacleDetected
2: | isDistanceCritical ← (usonicDistanceV alue < dthresh)
3: | if isDistanceCritical and irLef tIsObstacle and irRightIsObstacle then
4: | return true | ▷ Obstacle detected in front
5: | else
6: | return false | ▷ No obstacle detected
7: | end if
8: end procedure

9. Communication Hub

## 9. Communication Hub

The ESP32-S3-DevKitC-1 board, shown in Fig. 4, was used as the central communication and control hub, enabling efficient data exchange between the two-wheeled mobile base, the ToF sensor array, and external systems such as computers, microcontrollers, mobile devices, or cloud services, as illustrated in Fig. 8.

### 9.1. Communication with the Mobile Base

A custom communication protocol was developed to manage the exchange of control commands and telemetry data, which is structured around well-defined command and telemetry packets, implemented in comm.hpp. These packets support multiple data formats, ensuring compatibility with various communication protocols. Users can send commands to the mobile base and receive real-time telemetry feedback from the mobile base by using the provided member functions comm.hpp using communication protocols such as Inter-Integrated Circuit (I2C) and Universal Asynchronous Receiver-Transmitter (UART).
Inter-Integrated Circuit (I2C) communication is used for short-range, two-wire serial communication. The robot operates as an I2C slave with a predefined address (SLAVE_ADDR = 8), allowing it to

receive commands and transmit telemetry data over the I2C bus from the I2C master. The functions responsible for sending and receiving telemetry data are listed in Table 2.

Table 2: I2C Communication Methods
Packet Type | Function | Description
Command Packets | sendI2CBytes(addr) | Sends command data as raw bytes to the address.
| sendI2CASCII(addr) | Sends command data as ASCII to the address.
| readI2CBytes(addr) | Reads command data as raw bytes from the address.
| readI2CASCII(addr) | Reads command data as ASCII from the address.
Telemetry Packets | sendI2CBytes() | Sends telemetry data as raw bytes.
| sendI2CASCII() | Sends telemetry data as ASCII.
| readI2CBytes(addr) | Reads telemetry data as raw bytes from the address.
| readI2CASCII(addr) | Reads telemetry data as ASCII from the address.

The Universal Asynchronous Receiver-Transmitter (UART) protocol is used for serial communication.

The UART communication is initialized at a baud rate of 9600, which is used for the Bluetooth module used in this project [33]. The functions responsible for sending and receiving telemetry data are listed

in Table 3. For this project, UART communication was used as it was found to be more reliable.

### 9.1.1. Sending Commands

Users can send commands to control the robot’s movement, rotation, or stop function. Commands follow a predefined structured format and can be transmitted via either I2C or UART. The available

commands are listed in Table 4.
ASCII Format: The commands sent in ASCII is formatted as a comma-separated string:

<command>,<command_value>,<command_speed>

9. Communication Hub

Table 3: UART Communication Methods
Packet Type | Function | Description
Command Packets | readUartBytes() | Reads command data as raw bytes.
| readUartASCII() | Reads command data as an ASCII string.
| sendUartBytes() | Sends command data as raw bytes.
| sendUartASCII() | Sends command data as an ASCII string.
Telemetry Packets | sendUartBytes() | Sends telemetry data as raw bytes.
| sendUartASCII() | Sends telemetry data as an ASCII string.
| readUartBytes() | Reads telemetry data as raw bytes.
| readUartASCII() | Reads telemetry data as an ASCII string.

Table 4: List of Commands and Corresponding Values
Command | Value | Description
Stop | 0 | Stops the robot’s movement. Range: -32,768 to 32,767
Move | 1 | Moves forward or backward (in cm) at a given speed. Range: -32,768 to 32,767
Rotate | 2 | Rotates the robot by an angle (in degrees) at a given speed. Range: 0 to 359
INVALID | 3 | Represents an invalid or unrecognized command. Range: -32,768 to 32,767

Example Command:

- Stop the robot: 0,0,0
- Move forward 100 cm at 50% speed: 1,100,50
- Rotate 90° at 30 speed%: 2,90,30

### 9.1.2. Receiving Telemetry Data

The robot continuously monitors its state and environment using onboard sensors. This data is packaged into a structured format and transmitted back to the user for real-time monitoring and feedback. Telemetry data includes:

- Yaw Angle: The robot’s current orientation around the y-axis shown in Fig. 32 in degrees.
- Distance Travelled: The total distance travelled by the robot in centimetres.
- Ultrasonic Distance: The distance to the nearest obstacle, as measured by the ultrasonic sensor in centimetres.
- Left IR Sensor: Digital signal indicating detection of a persistent obstacle by the left sensor.
- Right IR Sensor: Digital signal indicating detection of a persistent obstacle by the right sensor.
- Left Motor Encoder Pulses: Total number of pulses recorded by the left wheel’s encoder.
- Right Motor Encoder Pulses: Total number of pulses recorded by the right wheel’s encoder.

9. Communication Hub

ASCII Format: The telemetry data received in ASCII is formatted as a comma-separated string:

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

Example Output:

4 5 , 2 0 0 , 3 0 , 1 , 0 , 1 5 4 0 , 1 5 7 2

This indicates:

- A yaw angle of 45 degrees
- A total distance travelled of 200 cm
- An ultrasonic measures an obstacle at a distance of 30 cm ahead
- The left IR sensor detects an obstacle (1)
- The right IR sensor does not detect an obstacle (0)
- 1540 total encoder pulses on the left motor
- 1572 total encoder pulses on the right motor

### 9.2. Communication with TerraRanger Multiflex

The TerraRanger Multiflex communicates via UART, transmitting raw data for all eight sensors in ASCII format. The data string begins with the prefix ’MF’ and is separated by tab characters, as

shown below:

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

In this format, each ‘<Sensor n>’ represents the distance measured by the corresponding sensor in millimeters. The actual raw data received over UART from the TerraRanger Multiflex is illustrated

in Fig. 29.

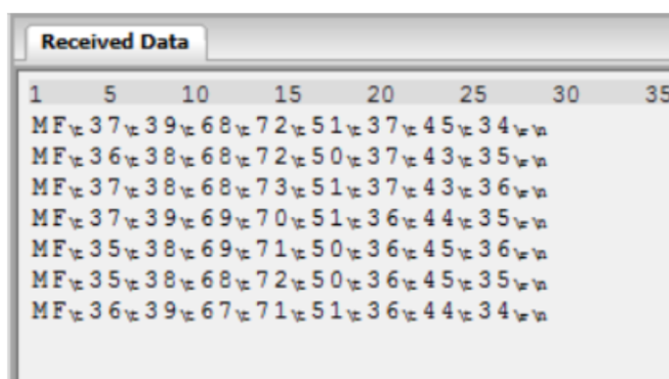
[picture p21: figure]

Figure 29: The received raw data from the TerraRanger Multiflex via UART.

9. Communication Hub

### 9.3. Communication with External Systems

The ESP32-S3 microcontroller is configured to operate in Soft Access Point (SoftAP) mode, enabling

it to create a dedicated Wi-Fi network. This configuration allows external devices, such as a remote PC or handheld controller, to connect directly to the ESP32-S3 without requiring an intermediary router. Once connected, the ESP32-S3 facilitates two-way communication between the robot and the external system by transmitting telemetry data and receiving control commands, as illustrated in Fig. 8.

### 9.3.1. Telemetry Transmission

To support real-time monitoring, the ESP32-S3 establishes a persistent TCP socket connection with a remote PC server. Sensor data—including measurements from the TerraRanger Multiflex (ToF sensors) and the mobile base—is read via UART interfaces. The received ASCII strings are then

transmitted to the remote PC server. The system ensures low-latency updates and verifies the connection status before each transmission to maintain data integrity. Fig. 30 illustrates the real-time visualization of the received telemetry in a polar plot.

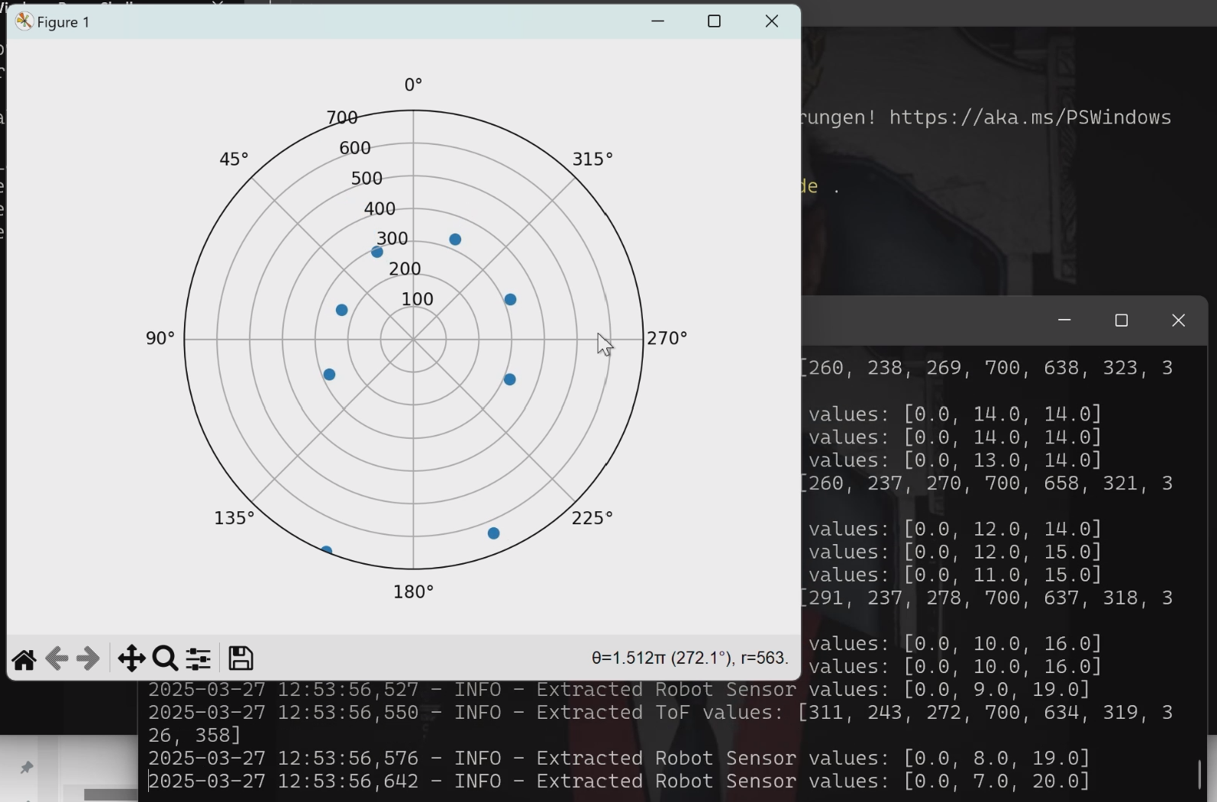
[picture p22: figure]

Figure 30: Real-time sensor data visualization in a polar plot.

### 9.3.2. Remote Command Reception and Execution

The ESP32-S3 also supports command reception over TCP from a connected external device. This mechanism allows remote users to control the mobile robot in real time. The workflow for command handling is described below:

1. TCP Listening: The ESP32-S3 continuously monitors its TCP server for incoming client connections.

9. Communication Hub
2. Command Reception: Once a client is connected, the ESP32-S3 reads the incoming ASCII-encoded command string. This string typically contains a command type (e.g., MOVE, ROTATE, STOP), a command value (e.g., angle or distance), and an associated speed parameter.
3. Parsing and Validation: The received string is parsed to extract individual parameters. These parameters are then encapsulated into a structured data packet.
4. UART Transmission to Robot: The formatted command packet is transmitted to the mobile base via UART.
5. Command Execution: The ESP32-S3 supports the reception of remote control commands transmitted over a TCP socket in the form of structured ASCII strings. The available commands are listed in Table 4. These commands are formatted as comma-separated values, representing the action to be performed, its magnitude, and the execution speed. A typical command string follows the pattern:
| <COMMAND>,<VALUE>,<SPEED>
6. Client Disconnection: After command execution, the ESP32-S3 acknowledges the command

and closes the client connection.

This bidirectional communication model enables seamless remote control and continuous monitoring, making it suitable for autonomous robotic applications and teleoperation scenarios.

10. Conclusion

## 10. Conclusion

This project aimed to design and implement a cost-effective, two-wheeled self-balancing robot integrated with a Time-of-Flight (ToF) sensor array for 2D environmental mapping and remote

control via Wi-Fi. The final assembly of the robot is depicted in Fig. 31.

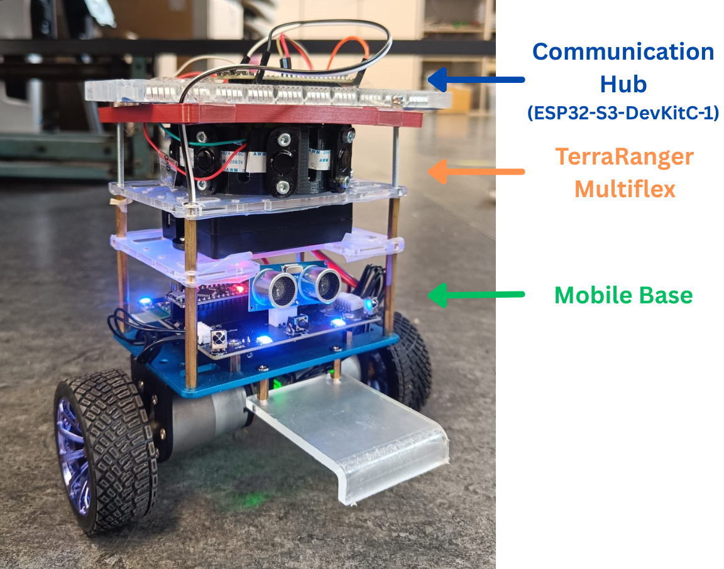
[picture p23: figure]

Figure 31: Final assembly of the remotely operated two-wheeled robot with TeraRanger Multiflex.

Control strategies were implemented using a multi-rate PID controller and Kalman filtering to ensure robust balance and motion control. The communication framework utilized TCP sockets over SoftAP Wi-Fi mode, enabling real-time telemetry streaming and command reception from remote systems. This architecture effectively demonstrates how low-cost components and open-source development environments can be harnessed to build intelligent robotic platforms capable of real-world interaction and monitoring.
Overall, the project successfully achieved its core objectives by integrating balancing control, environmental sensing, and networked communication into a unified robotic platform. The result is a versatile and extensible robot suitable for future enhancements such as autonomous navigation, SLAM integration, and multi-agent collaboration. All source code and documentation are publicly available to facilitate reproducibility and continued research in this domain.

11. Future Work and Improvements

## 11. Future Work and Improvements

The current system establishes a robust framework for real-time monitoring and control of a self-balancing robot equipped with a TeraRanger Multiflex sensor array. Future enhancements will focus on improving autonomy, robustness, and intelligence.
Advanced control strategies such as Model Predictive Control (MPC), adaptive PID, or reinforcement

learning will be investigated to improve stability and responsiveness under dynamic conditions. For full autonomy, integration of Simultaneous Localization and Mapping (SLAM) and path-planning

algorithms will enable real-time navigation and obstacle avoidance in complex environments.
Sensor capabilities will be extended by incorporating vision systems and additional IMUs, with multi-sensor fusion improving spatial awareness and decision-making. ROS2 integration is planned to enable modular software development, interoperability with other robotic platforms, and enhanced scalability.
Deploying lightweight machine learning models on the robot’s microcontroller could enable intelligent behavior and real-time adaptation to dynamic environments. This would allow the robot to make decisions based on sensor data locally, reducing reliance on remote processing and improving overall responsiveness.
Long-term goals include multi-robot coordination through swarm robotics, requiring decentralized communication and task allocation frameworks. Finally, embedding lightweight machine learning models on-device will facilitate local inference and adaptive behavior, reducing reliance on external computation and enhancing system responsiveness.

A. Calculation of the system’s transfer functions

# Appendices

## A. Calculation of the system’s transfer functions

Following modelling approach by Prasad and Tyagi [20], and MathWorks [8], we simplify the model

and represent it as an inverted pendulum connected to a wheel that moves in one direction. The wheelbase of robot is assumed to be sliding on a frictionless surface along x-axis, as shown in Fig. 5.

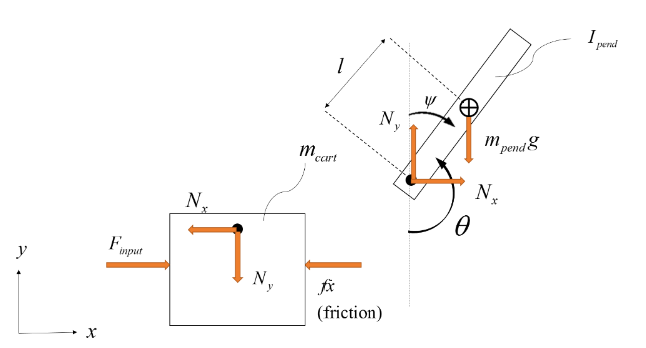
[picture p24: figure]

Figure 32: Free-body diagram of the simplified system with cart and pendulum [35]. Where, x axis is along the horizontal axis and y axis is along the vertical axis and ψ = π − θ.

A.1. Equation for the cart

The sums forces acting in the x direction on the cart is given by

Finput = mcartx¨ + fx˙ + Nx | (27)

where Nx is the contact force acting along the x-axis between cart and pendulum, f is a constant representing friction, mcart denotes mass of the cart, and Finput represents the applied force as shown in Fig. 32.

A.2. Equation for the the pendulum

The sum of forces acting in the x direction on the pendulum is given by

Nx = mpendx¨ + mpendl

¨θ cos θ − mpendl

˙θ
2
sin θ | (28)

where θ is the angle between a vertical y-axis and the pendulum, and mpend is the mass and l is distance to the centre of mass as shown in Fig. 32. The sum of all forces perpendicular to the pendulum is

Ny sin θ + Nx cos θ = mpendg sin θ − mpendl

¨θ + mpend ˙θ
2
cos θ | (29)

where Ny is the normal force acting along the y direction and g is the value for gravitational acceleration.

A. Calculation of the system’s transfer functions

The sum of torques acting on the centre of pendulum is given by

−Nylsin θ − Nxl cos θ = Ipend ¨θ | (30)

where Ipend denotes pendulum’s moment of inertia.

A.3. Combining the equations

By combining equations (28) and (29) gives the following equation,

Finput = (mcart + mpend)ẍ + fx˙ + mpendl

¨θ cos θ − mpendl

˙θ
2
sin θ | (31)

By combining equations (30) and (31) gives the following equation,

(Ipend + mpendl

2
)
¨θ + mpendglsin θ = −mpendlx¨ cos θ | (32)

A.4. Linearising the equations

If the pitch angle ψ represent the deviation of pendulum from equilibrium, as shown in Fig. 32, the following approximations for small deviations can be made

cos θ = cos(π + ψ) ≈ −1 | (33)
sin θ = sin(π + ψ) ≈ −ψ | (34)

˙θ

2 = ψ˙² ≈ 0 | (35)

Using approximations (33), (34) and (35) the non-linear equations (31) and (32) can be linearised to

following approximated equations

(Ipend + mpendl

2

)ψ¨ − mpendglψ = mpendlx¨ | (36)
uinput = (mcart + mpend)ẍ + fx˙ − mpendlψ¨ | (37)

where uinput is control effort of the system and replaces Finput in equation (31).

A.5. Laplace transform

The Laplace transforms of equations (36) and (37) are given by

(Ipend + mpendl

2
)Ψ(s)s

2 − mpendglΨ(s) = mpendlX(s)s

2
(38)

Uinput(s) = (mcart + mpend)X(s)s

2 + fX(s)s − mpendlΨ(s)s

2
(39)

A. Calculation of the system’s transfer functions

Solving equation (38) for X(s) gives

X(s) = "
Ipend + mpendl

2

mpendl

−

g
s

2

Ψ(s) | (40)

Substituting equation (40) into (39) gives

Uinput(s) =(mcart + mpend)

"
Ipend + mpendl

2

mpendl

−

g
s

2

Ψ(s)s

2

+ f

"
Ipend + mpendl

2

mpendl

−

g
s

2

Ψ(s)s − mpendlΨ(s)s

2

(41)

By rearranging equation (41) the transfer function GΨ(s) that describes the cart position Ψ(s) is given

by
GΨ(s) = Ψ(s) Uinput(s)
(42)

Ψ(s) =

mpendl
q

s

s

3 +

f(Ipend+mpendl

2)
q

s

2 −

(mcart+mpend)mpendgl
q

s −

fmpendgl
q
| | {z | }
| GΨ(s)
Uinput(s) | (43)

Where,

q = [(mcart + mpend)(Ipend + mpendl

2
) − (mpendl)

2
] | (44)

The transfer function Gx(s) that describes the cart position X(s) is given by

Gx(s) = X(s)

Uinput(s)

(45)

X(s) =

(Ipend+mpendl

2
)s

2−gmpendl
q
s

4 +

f(Ipend+mpendl

2)
q

s

3 −

(mcart+mpend)mpendgl
q

s

2 −

fmpendgl
q

s
| | {z | }
| Gx(s)
Uinput(s) | (46)

A.6. State Space Modelling

The system in state space form is represented as

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
+ Buinput | (47)
y = C uinput | (48)

B. Calculation for Kalman Filter

The system matrices A, B and C can be derived by solving Eq. 36 and Eq. 37:

A =

0 | 1 | 0 | 0
0 | −(Ipend+mpendl

2
)f
| Ipend(mcart+mpend)+mcartmpendl

2

m²

| | pendgl² Ipend(mcart+mpend)+mcartmpendl
2 | 0
0 | 0 | 0 | 1
0 | −mpendlf Ipend(mcart+mpend)+mcartmpendl
2
| | mpendgl(mcart+mpend) Ipend(mcart+mpend)+mcartmpendl
2 | 0

(49)

B =

0

Ipend+mpendl

2

Ipend(mcart+mpend)+mcartmpendl

2
0

mpendl
Ipend(mcart+mpend)+mcartmpendl

2

(50)

C =

"
1 0 0 0

0 0 1 0#
(51)

## B. Calculation for Kalman Filter

Using Kalman Filtering technique discussed by Pengfei Gui et al. [15] we can derived following

mathematical equations for IMU data fusion. The state equation and the estimate equation of the system based on the derivative relation of slant angle and angular velocity can be establish as following,

ψnew = ψprevious + (ψ˙ − ψ˙
b) ∗ ∆t

y = ψ

(52)

Then state-space representation of the system is given by,

x˙(t) = A x(t) + B uinput

y(t) = C x(t) + D uinput

(53)

Where,

- State Vector: This vector encapsulates the internal state of the system at time t. In this case, it is defined as:
x(t) = "
ψ
ψ˙
b
(54)

Where ψ˙
b denotes the bias or drift error of the gyroscope.
- Control Vector: This vector represents the external input given to the control-input model at step k. In this case,

uinput = ψ˙
gyro | (55)

Where, ψ˙
gyro is the pitch angular velocity measured by gyroscope.
- State Transition Model: This matrix describes how the state evolves over time. It is defined as:

A =

"
0 −1

0 0 #
(56)

B. Calculation for Kalman Filter

The first row indicates that the angle is updated based on its previous value, and the second row shows that the gyroscope bias remains constant in this model.

- Control Input Model: This matrix relates the control inputs to the state. In this case, it is defined as:

B =

"
1
0
(57)

This indicates that the angle is the only direct control inputs affecting the state in this model.

- Measurement Model: This matrix maps the state vector to the measurement output. It is defined as:
C =

h

1 0i
(58)

This means that the measurement output directly reflects the angle, with no contribution from the gyroscope bias.

- Feed-forward Model: This matrix relates the control input directly to the measurement output. In this case, it is defined as:
D = 0 | (59)

This indicates that there is no direct influence of the control input on the measurement output.

B.1. Time-Discrete Kalman Filter Model

The Kalman filter model assumes the true state xk at time k is evolved from the state xk−1 at k − 1

according to,
xk = G(∆t) xk−1 + H(∆t) uk−1 + dk | (60)

Similarly, at time k an observation (or measurement) zk of the true state xk is given by,

zk = Ck xk + nk | (61)

Where,

- Discrete State Vector:

xk =

"
ψk
ψ˙

b,k#
(62)

Where ψk represents the measured angle of the system and ψ˙
b,k denotes the error or bias of the gyroscope.
- State Transition Model: The State transition matrix G propagates the state xk−1 at sample k − 1 to the state at sample k. It captures all of the relevant internal dynamics of the system

by describing how each state moves over one sample time ∆t. It can be derived from State Transition Matrix A by applying the principles of discretization as following,

G(∆t) = e

A∆t
(63)

B. Calculation for Kalman Filter

Because matrix A is a Nilpotent matrix therefore,

G(∆t) = I + A∆t =

"
1 −∆t

0 1 #
(64)
- Control Input Model: The control input uinput into the system is accounted for with the control matrix H
H(∆t) = B

Z ∆t

0

e

Aσdσ | (65)

Because matrix A is a Nilpotent matrix therefore,

H(∆t) = "
∆t

0

(66)
- Measurement Model: The measurement matrix C for discrete model remains the same,

Ck =

h

1 0i
(67)
- Process/System Noise:

dk represents process noise which is Gaussian distributed with a zero mean and with covariance Qk at the time step k,
dk ∼ N(0, Qk) | (68)

In this case we will consider the estimate of the bias and the accelerometer to be independent, so it’s actually just equal to the variance of the estimate of the accelerometer and bias. So the process noise covariance matrix can be written as,

Qk =

"
Qψ | 0
0 | Qψ˙
b
∗ ∆t | (69)

Where covariance matrix Qk depends on the current time k, so the accelerometer variance Qψ and the variance of the bias Qψ˙
b

is multiplied by the delta time.

- Measurement Noise: n(k) represents measurement noise at time step k which is Gaussian

distributed as well with a zero mean and Rk as the covariance,

nk ∼ N(0, Rk) | (70)

In this case, Rk the measurement noise matrix is equal to the variance of the measurement, since the covariance of same variable is equal to the variance. We can define Rk as,

Rk = E

h
nk nk

T

i
= var(nk) | (71)

Where, E is the expectation operator. We can be assumed that the measurement noise is the same and does not depend on the time k,

var(nk) = var(n) = Rψ | (72)

B. Calculation for Kalman Filter

Where, Rψ is constant and provided by the manufacturer of sensor.

B.2. Implementing Kalman Filter

The Kalman filter is a recursive estimator, which requires only the estimated state from the previous time step k − 1 and the current measurement to compute the estimate state for the current time step

k.

B.2.1. Predicted State Estimate

A priori estimate of the angle xˆk|k−1 is made according to following relationship,

xˆk|k−1 = G xˆk−1|k−1 + H ψ˙
gyro,k | (73)

Where, xˆk−1|k−1

is the estimate of the state at previous step k − 1, and ψ˙ gyro,k is the angular velocity measured by the gyroscope at current step k.

B.2.2. Predicted Error Covariance

The state covariance matrix P is given by,

P =

"
P00 | P01
P10 | P11#
(74)

The matrix P reflects the uncertainties in the angle estimate (P00), the gyroscope bias (P11), and the cross-covariance terms (P01, P10). The a priori error covariance matrix Pk|k−1 can be estimated based

on the previous error covariance matrix Pk−1|k−1 as,

Pk|k−1 = G Pk−1|k−1G

T + Qk | (75)

This further expands to,

Pk|k−1 =

"
P00 | P01
P10 | P11#

k|k−1

=

"
P

−
00 + [(Qψ + ∆tP11 − P

−
01 − P

−
10) ∗ ∆t] P

−
01 − (P

−
11 ∗ ∆t)

P

−
10 − (P

−
11 ∗ ∆t) | P

−
| 11 + (Qψ˙
b

∗ ∆t)

(76)

Where the negative sign (e.g. " - ") on top of P

−
00, P

−
10, P

−
11 and P

−
01 represents that these parameters were calculated using previous step k − 1 values. The initial state covariance matrix is defined as,

P0 =

"
1 0

0 1#
(77)

B.2.3. Innovation Residual

The innovation residual y˜k is the difference between the output of the sensor, zk, and the predicted state, xˆk|k−1

, rotated into the sensor output frame with Ck

y˜k = zk − Ck xˆk|k−1

(78)

11. Calculation for Kalman Filter

B.2.4. Innovation Covariance

The innovation covariance Sk is the sum of the prediction covariance P, and the measurement covariance R,

Sk = C Pk|k−1 C

T + Rk

=

h

1 0i

"
P00 | P01
P10 | P11#

k|k−1

"
1
0
+ Rψ

Sk = P00,k|k−1 + Rψ

(79)

B.2.5. Optimal Kalman Gain

We can find optimal Kalman gain matrix Kk as,

Kk = Pk|k−1 C

T
k S

−1
k

(80)

It determines much the state estimate should be adjusted based on the measurement residual. It balances the uncertainty in the state estimate and the measurement noise. The Kalman gain Kk is computed as,

Kk = Pk|k−1 C

T S

−1
k

=

"
P00 | P01
P10 | P11#

k|k−1

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
P10#

k|k−1

(P00 + Rψ)

−1

Kk =

"
K0
K1
=

P00
P00+Rψ

P10
P00+Rψ

(81)

B.2.6. Corrected State Estimate

The corrected state estimate is somewhere between the predicted state xk|k−1 and the measurement y˜k, and is calculated as,
xˆk|k = ˆxk|k−1 + Kk y˜k | (82)

B.2.7. Corrected Estimate Covariance

The estimate covariance matrix is corrected as,

Pk|k = (I − Kk C) Pk|k−1

=

"1 0

0 1#
−

"
K0
K1
h

1 0i

! "P00 | P01
P10 | P11#

k|k−1

=

"
1 − K0 | 0
−K1 | 1
# "P00 | P01

P10 | P11#

k|k−1

=

"
P00 − K0 · P00 | P01 − K0 · P01
P10 − K1 · P00 | P11 − K1 · P01#

(83)

11. References

## References

[1] I. I. F. o. Robotics. “Record of 4 million robots in factories worldwide”, IFR International Federation of Robotics, Accessed: Apr. 7, 2025. [Online]. Available: https://ifr.org/ifr-

press-releases/news/record-of-4-million-robots-working-in-factories-worldwide. (https://ifr.org/ifr-press-releases/news/record-of-4-million-robots-working-in-factories-worldwide)

[2] C. E. Staff. “Autonomous mobile robot market expanding at record pace”, Control Engineering,

Accessed: Apr. 8, 2025. [Online]. Available: https : / / www . controleng . com / autonomous -

mobile-robot-market-expanding-at-record-pace/. (https://www.controleng.com/autonomous-mobile-robot-market-expanding-at-record-pace/)

[3] S. Wagner, “2d materials for piezoresistive strain gauges and membrane based nanoelectromechanical

systems”, Ph.D. dissertation, Dissertation, RWTH Aachen University, 2018, 2018.

[4] “Global MEMS market size, share, analysis-2032”, Spherical Insights, Accessed: Apr. 8, 2025.

[Online]. Available: https://www.sphericalinsights.com/reports/mems-market.

[5] M. Bjelonic, V. Klemm, J. Lee, and M. Hutter, “A survey of wheeled-legged robots”, in Robotics

in Natural Settings, J. M. Cascalho, M. O. Tokhi, M. F. Silva, A. Mendes, K. Goher, and M. Funk, Eds., Cham: Springer International Publishing, 2023, pp. 83–94.

[6] D. Kim, W. Chung, and S. Park, “Practical motion planning for car-parking control in narrow

environment”, IET control theory & applications, vol. 4, no. 1, pp. 129–139, 2010.

[7] ELEGOO Official, Elegoo tumbller self-balancing robot car v1.1/v1.0 tutorial, Accessed: 2025-

02-15. [Online]. Available: https : / / www . elegoo . com / blogs / arduino - projects / elegoo -

tumbller-self-balancing-robot-car-tutorial. (https://www.elegoo.com/blogs/arduino-projects/elegoo-tumbller-self-balancing-robot-car-tutorial)

[8] MATLAB, Inverted pendulum: System modeling, Accessed: 2025-02-15. [Online]. Available:

https://ctms.engin.umich.edu/CTMS/index.php?example=InvertedPendulum&section=

SystemModeling. (https://ctms.engin.umich.edu/CTMS/index.php?example=InvertedPendulum&section=SystemModeling)

[9] N. S. Nise, Control systems engineering. John Wiley & Sons, 2020.
[10] K. M. Passino, S. Yurkovich, and M. Reinfrank, Fuzzy control. Addison-wesley Reading, MA,

1998, vol. 42.

[11] A. Abdelgawad, T. Shohdy, and A. Nada, “Model-and data-based control of self-balancing

robots: Practical educational approach with labview and arduino”, IFAC-PapersOnLine, vol. 58,

no. 9, pp. 217–222, 2024.

[12] R. E. Kalman, “A new approach to linear filtering and prediction problems”, 1960.
[13] P. Chotikunnan et al., “Comparative analysis of sensor fusion for angle estimation using kalman

and complementary filters”, International Journal of Robotics and Control Systems, vol. 5, no. 1,

pp. 1–21, 2024. [Online]. Available: https : / / www . pubs2 . ascee . org / index . php / IJRCS /

article/view/1674. (https://www.pubs2.ascee.org/index.php/IJRCS/article/view/1674)

[14] H.-Q.-T. Ngo, T.-P. Nguyen, V.-N.-S. Huynh, T.-S. Le, and C.-T. Nguyen, “Experimental

comparison of complementary filter and kalman filter design for low-cost sensor in quadcopter”, in 2017 International Conference on System Science and Engineering (ICSSE), IEEE, 2017,

pp. 488–493.

11. References
[15] P. Gui, L. Tang, and S. Mukhopadhyay, “Mems based imu for tilting measurement: Comparison

of complementary and kalman filter based data fusion”, in 2015 IEEE 10th Conference on Industrial Electronics and Applications (ICIEA), 2015, pp. 2004–2009.

[16] Mouser Electronics, Teraranger multiflex key features applications, https : / / mouser . com /

datasheet/2/944/MultiflexSpecificationSheet-1880070.pdf, (https://mouser.com/datasheet/2/944/MultiflexSpecificationSheet-1880070.pdf) Accessed: 10 April 2025.

[17] ESP32-S3-DevKitC-1, [Online; accessed 10. Apr. 2025], 2025. [Online]. Available: https : / /

docs.espressif.com/projects/esp- dev- kits/en/latest/esp32s3/esp32- s3- devkitc-

1/user_guide.html. (https://docs.espressif.com/projects/esp-dev-kits/en/latest/esp32s3/esp32-s3-devkitc-1/user_guide.html)

[18] Thingiverse, Teraranger multiflex circular mount, Accessed: 2025-02-15. [Online]. Available:

https://www.thingiverse.com/thing:2311818.

[19] ESP32-S3-DEVKITC-1-N8R8 | DigiKey Electronics, [Online; accessed 10. Apr. 2025], Apr. 2025.

[Online]. Available: https://www.digikey.de/en/products/detail/espressif- systems/

ESP32-S3-DEVKITC-1-N8R8/15295894. (https://www.digikey.de/en/products/detail/espressif-systems/ESP32-S3-DEVKITC-1-N8R8/15295894)

[20] L. B. Prasad, B. Tyagi, and H. O. Gupta, “Optimal control of nonlinear inverted pendulum

system using pid controller and lqr: Performance analysis without and with disturbance input”, International Journal of Automation and Computing, vol. 11, no. 6, pp. 661–670, 2014. [Online].

Available: https://doi.org/10.1007/s11633-014-0818-1.

[21] Microchip, Atmega328p, Accessed: 2024-11-23. [Online]. Available: https://www.microchip.

com/en-us/product/ATmega328p. (https://www.microchip.com/en-us/product/ATmega328p)

[22] Arduino S.r.l., Arduino nano, Accessed: 2025-02-09. [Online]. Available: https : / / store .

arduino.cc/en-de/products/arduino-nano. (https://store.arduino.cc/en-de/products/arduino-nano)

[23] E. Official, Elegoo smart robot car kit v4.0 tutorial, Accessed: 2025-02-09. [Online]. Available:

https://www.elegoo.com/blogs/arduino-projects/elegoo-smart-robot-car-kit-v4-0-

tutorial. (https://www.elegoo.com/blogs/arduino-projects/elegoo-smart-robot-car-kit-v4-0-tutorial)

[24] InvenSense, Mpu-6050, Accessed: 2024-11-23. [Online]. Available: https://invensense.tdk.

com/products/motion-tracking/6-axis/mpu-6050/. (https://invensense.tdk.com/products/motion-tracking/6-axis/mpu-6050/)

[25] Toshiba, Tb6612fng, Accessed: 2024-11-23. [Online]. Available: https : / / toshiba . semicon -

storage.com/us/semiconductor/product/motor-driver-ics/brushed-dc-motor-driver-

ics/detail.TB6612FNG.html. (https://toshiba.semicon-storage.com/us/semiconductor/product/motor-driver-ics/brushed-dc-motor-driver-ics/detail.TB6612FNG.html)

[26] BerryBase - The Maker Shop, Sparkfun motor treiber, dual tb6612fng, mit headern, Accessed:

2025-02-09. [Online]. Available: https : / / www . berrybase . de / sparkfun - motor - treiber -

dual-tb6612fng-mit-headern. (https://www.berrybase.de/sparkfun-motor-treiber-dual-tb6612fng-mit-headern)

[27] Texas Instruments, Sn74lvc2g14, Accessed: 2024-11-23. [Online]. Available: https://www.ti.

com/product/SN74LVC2G14. (https://www.ti.com/product/SN74LVC2G14)

[28] Cadence Design Systems, Schmitt trigger hysteresis provides noise-free switching and output,

Accessed: 2025-02-09. [Online]. Available: https://resources.pcb.cadence.com/blog/2021-

schmitt-trigger-hysteresis-provides-noise-free-switching-and-output. (https://resources.pcb.cadence.com/blog/2021-schmitt-trigger-hysteresis-provides-noise-free-switching-and-output)
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

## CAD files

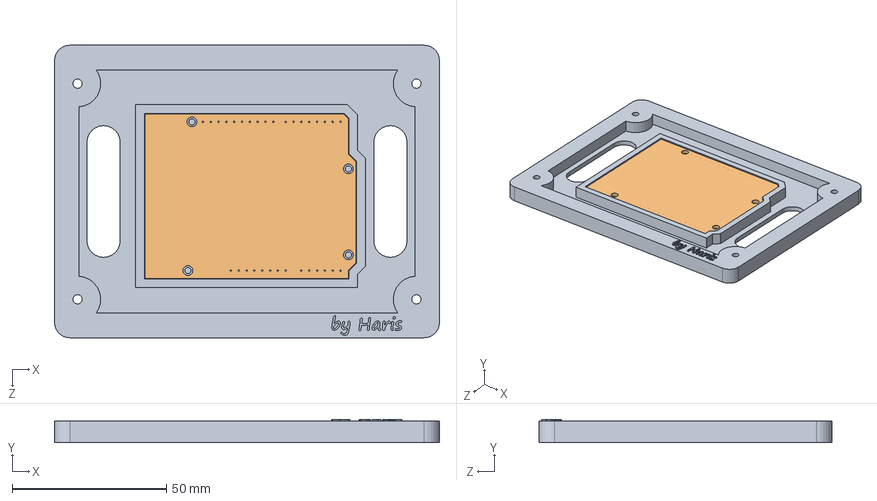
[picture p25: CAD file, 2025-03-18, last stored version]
3d_model/Assem.SLDASM
125.0 x 7.50 x 95.0 mm
elegoo_tumbler_attachment
Arduino UNO R3 shield - full

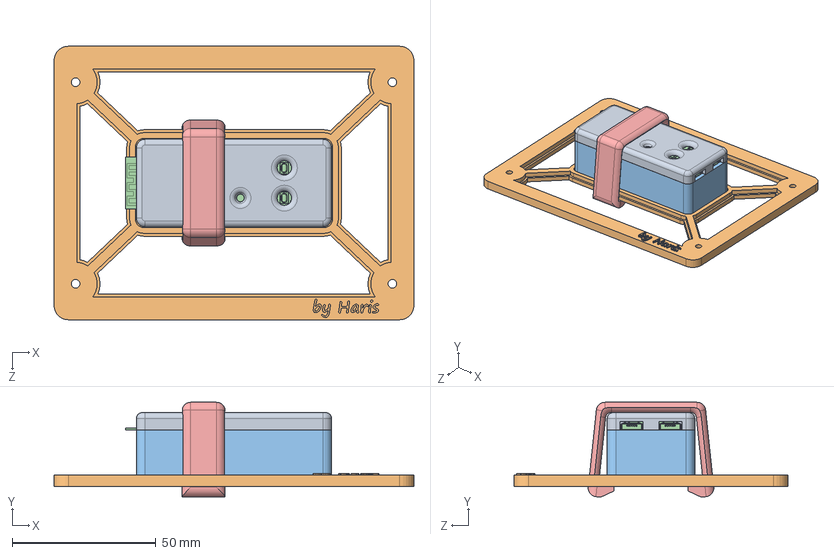
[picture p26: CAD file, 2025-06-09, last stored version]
3d_model/TerraRanger_and_ESP32_S3_DevKitC_1_attachment - Kopie/Assem.SLDASM
125.0 x 32.8 x 95.0 mm
Elegoo_Tumbler_Attachment
ESP32-S3-DEVKITC-1-Case
ESP32-S3-DEVKITC-1-N8R2--3DModel-STEP-56544
ESP32-S3-DEVKITC-1-Cap
ESP32-S3-DEVKITC-1-Clip

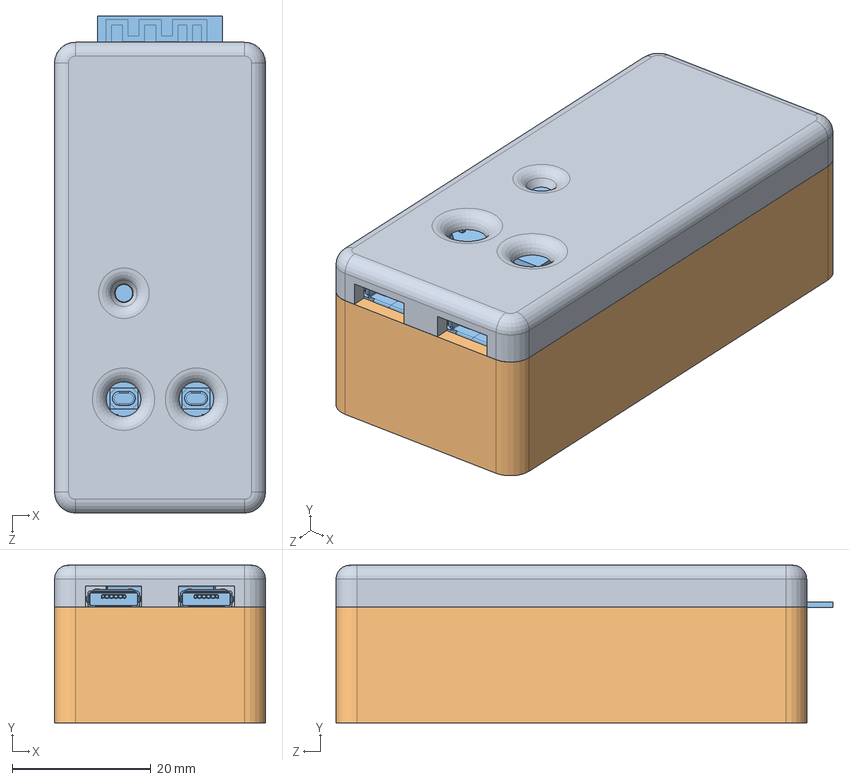
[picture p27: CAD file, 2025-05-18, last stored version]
3d_model/TerraRanger_and_ESP32_S3_DevKitC_1_attachment - Kopie/SubAssembly.SLDASM
30.4 x 22.7 x 71.6 mm
ESP32-S3-DEVKITC-1-Case
ESP32-S3-DEVKITC-1-N8R2--3DModel-STEP-56544
ESP32-S3-DEVKITC-1-Cap

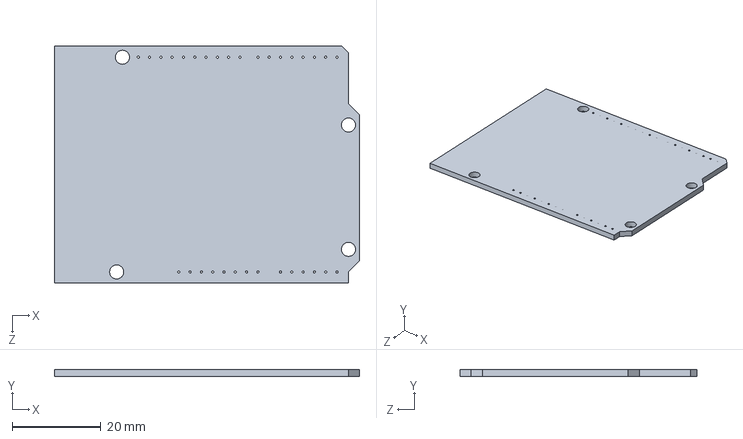
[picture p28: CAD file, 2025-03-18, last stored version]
3d_model/TerraRanger_and_ESP32_S3_DevKitC_1_attachment - Kopie/Arduino UNO R3 shield - full.sldprt
68.5 x 1.60 x 53.4 mm

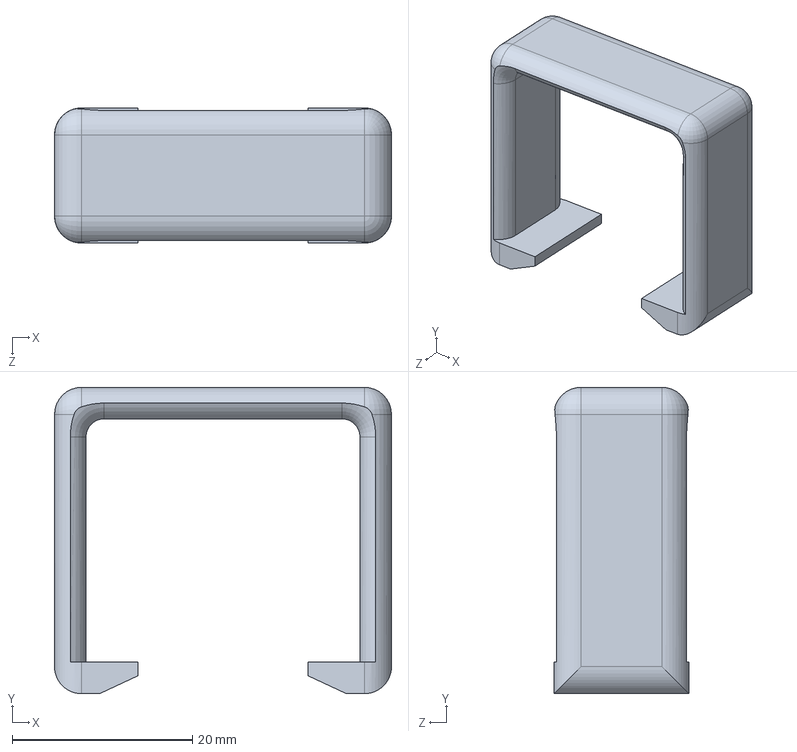
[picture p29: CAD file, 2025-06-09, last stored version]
3d_model/TerraRanger_and_ESP32_S3_DevKitC_1_attachment - Kopie/ESP32-S3-DEVKITC-1-Clip_v1.SLDPRT
37.4 x 34.0 x 15.0 mm

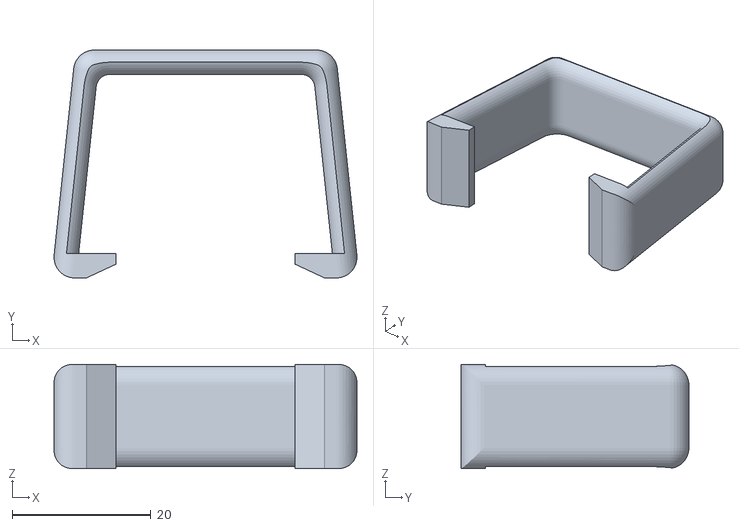
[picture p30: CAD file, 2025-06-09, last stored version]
3d_model/TerraRanger_and_ESP32_S3_DevKitC_1_attachment - Kopie/Clip_v2.STL
43.6 x 32.8 x 15.0

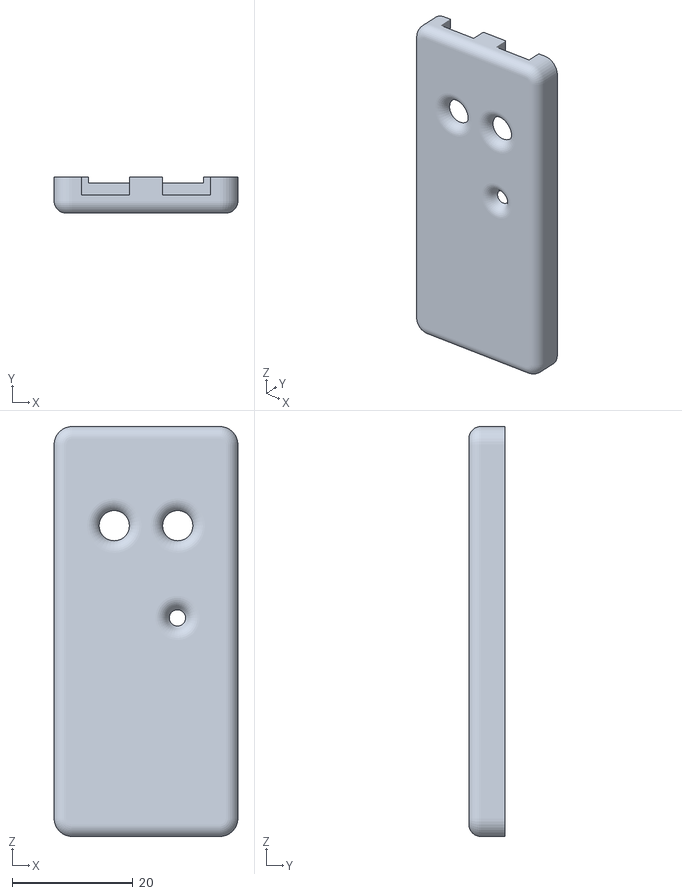
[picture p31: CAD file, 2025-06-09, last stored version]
3d_model/TerraRanger_and_ESP32_S3_DevKitC_1_attachment - Kopie/Cap.STL
30.4 x 6.00 x 67.8

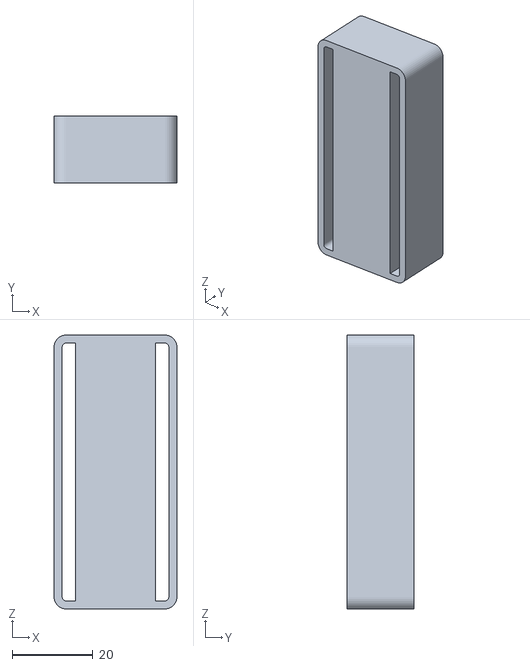
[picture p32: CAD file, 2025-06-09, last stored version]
3d_model/TerraRanger_and_ESP32_S3_DevKitC_1_attachment - Kopie/Case.STL
30.4 x 16.7 x 67.8

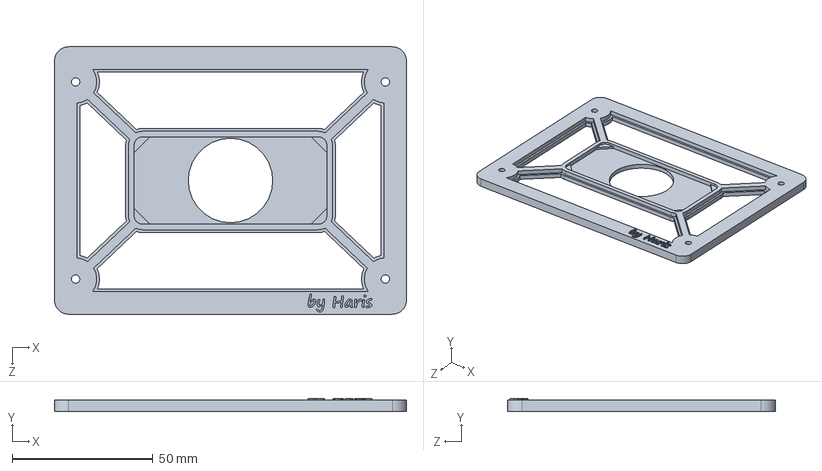
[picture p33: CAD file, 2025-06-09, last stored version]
3d_model/TerraRanger_and_ESP32_S3_DevKitC_1_attachment - Kopie/Elegoo_Tumbler_Attachment.SLDPRT
125.0 x 4.50 x 95.0 mm

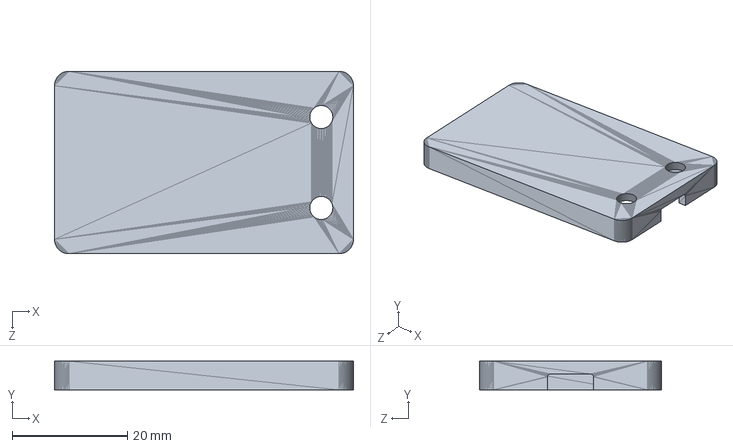
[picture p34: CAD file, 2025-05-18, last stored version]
3d_model/TerraRanger_and_ESP32_S3_DevKitC_1_attachment - Kopie/ESP-32_Dev_Kit_C_V4_case_cap_V2.SLDPRT
52.0 x 5.00 x 31.7 mm

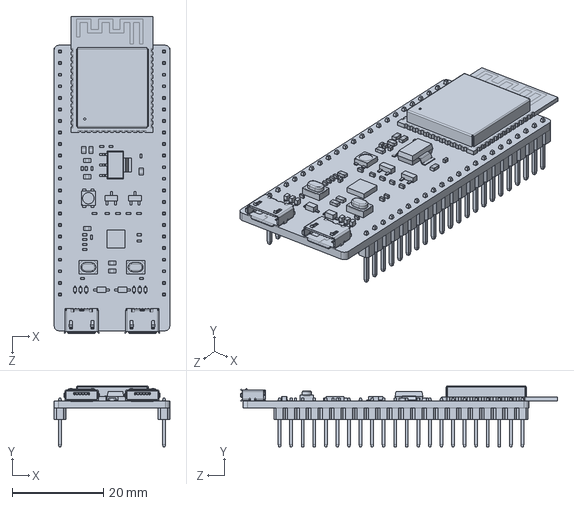
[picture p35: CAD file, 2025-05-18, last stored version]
3d_model/TerraRanger_and_ESP32_S3_DevKitC_1_attachment - Kopie/ESP32-S3-DEVKITC-1-N8R2--3DModel-STEP-56544.SLDPRT
25.4 x 13.4 x 69.6 mm

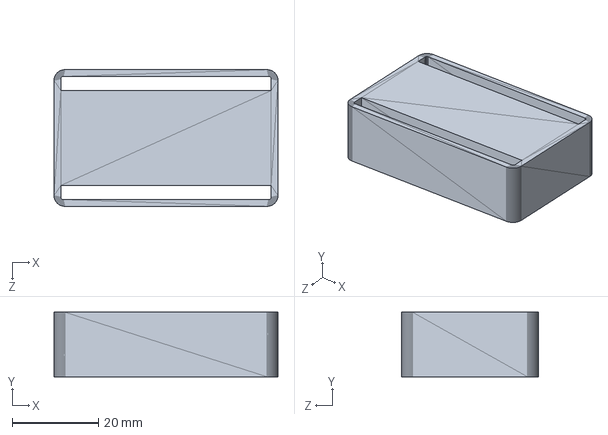
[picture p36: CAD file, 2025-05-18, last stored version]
3d_model/TerraRanger_and_ESP32_S3_DevKitC_1_attachment - Kopie/ESP-32_Dev_Kit_C_V4_case_V1.SLDPRT
52.0 x 15.0 x 31.7 mm

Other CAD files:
3d_model/TerraRanger_and_ESP32_S3_DevKitC_1_attachment - Kopie/ESP32-S3-DEVKITC-1-Clip.SLDPRT
3d_model/TerraRanger_and_ESP32_S3_DevKitC_1_attachment - Kopie/ESP32-S3-DEVKITC-1-Case.SLDPRT
3d_model/TerraRanger_and_ESP32_S3_DevKitC_1_attachment - Kopie/ESP32-S3-DEVKITC-1-Cap.SLDPRT
3d_model/TerraRanger_and_Arduino_UNO_attachment/elegoo_tumbler_attachment.STL
3d_model/TerraRanger_and_ESP32_S3_DevKitC_1_attachment - Kopie/elegoo_tumbler_attachment.STL
3d_model/elegoo_tumbler_attachment.STL

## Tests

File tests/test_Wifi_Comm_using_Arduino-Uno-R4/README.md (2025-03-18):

Allows for seamless communication between the Arduino and a client (such as a Python server or web application) over a Wi-Fi network.

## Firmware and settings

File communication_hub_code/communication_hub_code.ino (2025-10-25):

#include <WiFi.h>
#include <WiFiUdp.h> // Include for UDP communication
#include <HardwareSerial.h>
#include "comm.hpp" // Assuming this header defines TumblerCommand, commandPacket, and telemetryPacket

// Serial Ports
HardwareSerial sensorSerial(1); // Use UART1 for sensor
HardwareSerial robotSerial(2);  // Use UART2 for robot

// --- WiFi Configuration ---
const char* SSID = "ESP32-Control";
const char* PASSWORD = "controlpass";

// --- UDP Configuration ---
// ESP32 IP address when acting as an Access Point (AP)
// Python client will connect to this network and typically get 192.168.4.2
const IPAddress localIP(192, 168, 4, 1);
const IPAddress gateway(192, 168, 4, 1);
const IPAddress subnet(255, 255, 255, 0);

const unsigned int ESP_LISTEN_PORT = 12345; // Port the ESP will listen on for commands from Python
const unsigned int PYTHON_LISTEN_PORT = 12346; // Port on Python side to send telemetry data to (Python's listening port)

// Python client's IP address. This will be updated once Python sends its first command.
// For initial testing, you might hardcode it if you know your Python machine's IP
// on the ESP's AP network, e.g., IPAddress(192, 168, 4, 2);
IPAddress pythonClientIP;

WiFiUDP Udp; // UDP instance

// Data Structures (from comm.hpp)
commandPacket cmdData;
telemetryPacket teleData;

// --- Timing for Data Sending ---
unsigned long previousMillis = 0;
const long interval = 10; // Send data every 10 milliseconds

// --- Debugging ---
// Assuming DEBUG_COMM and DEBUG_PRINT are defined in comm.hpp or elsewhere
#ifndef DEBUG_COMM
#define DEBUG_COMM true // Define if not already defined
#endif
#ifndef DEBUG_PRINT
#define DEBUG_PRINT(flag, msg) do { if (flag) { Serial.println(msg); } } while (0)
#endif


// Function Prototypes
void setupWiFi();
void handleUdpCommands(); // Refactored from handleClientRequests
void processCommand(const String& command);
void sendTelemetryToPC(); // Refactored from sendDataToPC, integrated into forwardSensorData for 10ms loop
void forwardSensorData();

void setup() {
    Serial.begin(115200);
    sensorSerial.begin(115200, SERIAL_8N1, 18, 17); // RX, TX for sensor
    robotSerial.begin(115200, SERIAL_8N1, 16, 15);   // RX, TX for robot

    setupWiFi();

    // Initialize pythonClientIP to an invalid address initially
    pythonClientIP = IPAddress(0, 0, 0, 0);
}

void loop() {
    // Process incoming UDP commands from Python
    handleUdpCommands();

    // Read sensor data and attempt to send every 10ms
    forwardSensorData();    
}

// Initialize ESP32 as an Access Point and start UDP listener
void setupWiFi() {
    WiFi.softAPConfig(localIP, gateway, subnet); // Set static IP for AP
    WiFi.softAP(SSID, PASSWORD);

    DEBUG_PRINT(DEBUG_COMM, "Access Point started");
    DEBUG_PRINT(DEBUG_COMM, "ESP32 IP Address: " + WiFi.softAPIP().toString());

    Udp.begin(ESP_LISTEN_PORT);
    DEBUG_PRINT(DEBUG_COMM, "Listening for UDP commands on port: " + String(ESP_LISTEN_PORT));
}

// Handle incoming UDP commands from the PC
void handleUdpCommands() {
    int packetSize = Udp.parsePacket();
    if (packetSize) {
        // Read the packet into a temporary buffer
        char incomingPacketBuffer[255]; // Max UDP packet size is often 255-512 bytes for simple messages
        int len = Udp.read(incomingPacketBuffer, sizeof(incomingPacketBuffer) - 1);
        if (len > 0) {
            incomingPacketBuffer[len] = 0; // Null-terminate the string
        }

        // Store the sender's IP. This is our Python client.
        // We only need the IP, as the Python script will listen on a known port (PYTHON_LISTEN_PORT)
        pythonClientIP = Udp.remoteIP();
        // unsigned int remotePort = Udp.remotePort(); // Not strictly needed for sending back to a known port

        String clientMessage = String(incomingPacketBuffer);
        DEBUG_PRINT(DEBUG_COMM, "Received command from " + pythonClientIP.toString() +
                                 " -> " + clientMessage);

        processCommand(clientMessage);
    }
}

// Parse and process incoming commands (no change needed for UDP)
void processCommand(const String& commandStr) {
    String command = commandStr;
    command.trim();

    int comma1 = command.indexOf(',');
    int comma2 = command.indexOf(',', comma1 + 1);

    if (comma1 == -1 || comma2 == -1) {
        DEBUG_PRINT(DEBUG_COMM, "Invalid command format");
        return;
    }

    String cmd = command.substring(0, comma1);
    cmd.trim();
    int value = command.substring(comma1 + 1, comma2).toInt();
    int speed = command.substring(comma2 + 1).toInt();

    if (cmd == "TURN") {
        cmdData.command = TumblerCommand::Rotate;
    } else if (cmd == "MOVE") {
        cmdData.command = TumblerCommand::Move;
    } else if (cmd == "STOP") {
        cmdData.command = TumblerCommand::Stop;
    } else {
        DEBUG_PRINT(DEBUG_COMM, "Unknown command: " + cmd);
        return;
    }

    cmdData.commandValue = value;
    cmdData.commandSpeed = speed;
    cmdData.sendUartASCII(robotSerial); // Assuming this function exists and is correctly defined
    DEBUG_PRINT(DEBUG_COMM, "Processed command: " + cmd + " Value: " + String(value) + " Speed: " + String(speed));
}

// Read sensor data and prepare to send to PC via UDP
char lastTofData[128] = {0};
char lastRobotData[128] = {0};
char combinedData[256] = {0};

void forwardSensorData() {
    if (robotSerial.available()) {
        int len = robotSerial.readBytesUntil('\n', lastRobotData, sizeof(lastRobotData) - 1);
        lastRobotData[len] = '\0';
    }

    if (sensorSerial.available()) {
        int len = sensorSerial.readBytesUntil('\n', lastTofData, sizeof(lastTofData) - 1);
        lastTofData[len] = '\0';

        if (pythonClientIP != IPAddress(0, 0, 0, 0)) {
            snprintf(combinedData, sizeof(combinedData), "%s\nRB\t%s", lastTofData, lastRobotData);

            Udp.beginPacket(pythonClientIP, PYTHON_LISTEN_PORT);
            Udp.write((const uint8_t*)combinedData, strlen(combinedData));
            Udp.endPacket();

            DEBUG_PRINT(DEBUG_COMM, combinedData);
        }
    }
}

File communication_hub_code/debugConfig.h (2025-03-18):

#pragma once

// plot mode (for plotting pitch angle , yaw angle and position along with there correspoing pid output values)
#define PLOT_MODE false      

// Global debug mode (set to false to disable all debugging)
#define DEBUG_MODE true     
#if DEBUG_MODE
  // Module-specific debug modes
  #define DEBUG_MOTOR false     // Debugging for Motor Control module
  #define DEBUG_IMU false       // Debugging for IMU module
  #define DEBUG_KALMAN false    // Debugging for Kalman Filter alogrithm
  #define DEBUG_CONTROL false   // Debugging for Motion Controller alogrithm
  
  #if DEBUG_CONTROL
    #define DEBUG_VOLTAGE false   // Debugging for Communication module
    #define DEBUG_PID_PITCH false // Debugging for PID control for Pitch
    #define DEBUG_PID_YAW false // Debugging for PID control for Pitch
    #define DEBUG_PID_POSITION false  // Debugging for PID control for Pitch
    #define DEBUG_ENCODER false  // Debugging for Motor incremental encoders
    #define DEBUG_WATCHDOG false
  #endif

  #define DEBUG_COMM true   // Debugging for Communication module
  #define DEBUG_USONIC false // Debugging for Ultrasonic and IR modules
  #define DEBUG_TERRA_RANGER true // Debugging for TerraRanger Multiflex
#endif

// Macro for conditional debugging
#if DEBUG_MODE
#define DEBUG_PRINT(module, x) \
    if (module) { \
      Serial.print("[time:"); \
      Serial.print(String(millis())); \
      Serial.print("ms][Debug] "); \
      Serial.println(x); \
    }
#else
  #define DEBUG_PRINT(module, x)
#endif

#if PLOT_MODE
  #define SEND_FOR_PLOT(x) Serial.println(x);
#else
  #define SEND_FOR_PLOT(x)
#endif

// Macro for error messages (always active)
#define ERROR_PRINT(x) \
  do { \
    Serial.print("[time:"); \
    Serial.print(millis()); \
    Serial.print("ms][ERROR]"); \
    Serial.println(x); \
  } while(0)

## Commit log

2025-03-31 improved ESP32-S3 code
2025-03-31 rearranged files
    [Arduino UNO R3 shield - full.sldprt, Assem.SLDASM, elegoo_tumbler_attachment.STL]
2025-05-18 added ESP32 S3 case and updated telemetry packet
    1. added ESP32 S3 3d printable case
    2. added more sensor values to the telemetry packet
    [Arduino UNO R3 shield - full.sldprt, Assem.SLDASM, ESP-32_Dev_Kit_C_V4_case_V1.SLDPRT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]
2025-06-09 SLAM + Interactive GUI
    [Assem.SLDASM, Cap.STL, Case.STL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]
